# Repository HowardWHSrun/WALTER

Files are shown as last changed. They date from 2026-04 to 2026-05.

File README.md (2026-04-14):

# WALTER

**WALTER** = *Walking Alternating Tripod for Evolutionary Research* — a twelve-DOF hexapod (firmware, MuJoCo RL, CAD, and documentation).

**Authors (Engineering 90):** Howard Wang, Matthew Shiley  
**Advisor:** Allan Moser (Swarthmore College)

## Contents (repository map)

| Area | Path |
|---|---|
| Final report (PDF, LaTeX, figures) | [`final_report/`](final_report/) |
| Adaptive firmware and docs | [`adaptive_ondevice_hexapod/`](adaptive_ondevice_hexapod/) |
| MuJoCo PPO training code | [`hexapod_training_new/`](hexapod_training_new/) |
| Released checkpoints (zips) and eval helpers | [`e90_repo/`](e90_repo/) |
| Mid-semester presentation sources | [`Presentation/`](Presentation/) |

Training rollouts under `hexapod_training_new/runs/` are omitted from this repository to save space; regenerate with `train.py` and the configs in `hexapod_training_new/configs/`.

## Build the final report PDF

From `final_report/`:

```bash
pdflatex E90_Final_Report.tex
bibtex E90_Final_Report
pdflatex E90_Final_Report.tex
pdflatex E90_Final_Report.tex
```

A prebuilt `E90_Final_Report.pdf` is included. To regenerate the MuJoCo figure `mujoco_hexapod_sim.png`, install `mujoco` and `imageio`, `cd final_report`, and run `python3 render_mujoco_snapshot.py` (expects `../hexapod_training_new/assets/hexapod.xml` in this repository clone).

## License

Add a `LICENSE` file if you want explicit terms; otherwise default GitHub copyright applies.

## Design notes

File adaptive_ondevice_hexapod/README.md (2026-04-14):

# Adaptive on-device learning (hexapod)

**WALTER — canonical repository:** [https://github.com/HowardWHSrun/WALTER](https://github.com/HowardWHSrun/WALTER)  
*(Walking Alternating Tripod for Evolutionary Research. Consolidate firmware, docs, and CAD here for public release.)*

Bio-inspired hexapod that uses **IMU body-state feedback** to reflexively stabilize locomotion and **gradually adapt its gait** on-device, running entirely on a Teensy 4.1.

## Approach

Three layers, inspired by insect locomotion architecture:

1. **Innate rhythm** -- structured tripod gait (v2 lift/swing/plant keyframes).
2. **Sensory corrections** -- IMU-driven postural reflexes adjust leg targets in real time (roll/pitch stabilization, angular-velocity damping, cautious mode, push recovery).
3. **Online learning** -- slow adaptation of 5 reflex/gait parameters via SPSA or bandit search, minimizing a stability cost computed from IMU signals.

## Documentation

| Document | Contents |
|---|---|
| [docs/DESIGN.md](docs/DESIGN.md) | Biological motivation, what the IMU tells us, full behavior catalog (13 behaviors across 3 levels), limitations, references |
| [docs/ARCHITECTURE.md](docs/ARCHITECTURE.md) | Control loop diagram, IMU filter pseudocode, stability score, tuneable gait parameters, reflex rules, adaptation layer (SPSA), timing budget, safety limits |
| [docs/PHASES.md](docs/PHASES.md) | Four-phase implementation roadmap with concrete deliverables and exit criteria per phase |
| [docs/FIRMWARE.md](docs/FIRMWARE.md) | Hardware stack: Teensy 4.1, Pololu Maestro, 12 servos, channel map, Maestro protocol, joint-to-us mapping |

## Repo layout

| Path | Purpose |
|---|---|
| `docs/` | Design docs, architecture, roadmap, hardware reference |
| `firmware/hexapod_walking_v2/` | Baseline: hard-coded scripted tripod v2 gait (no adaptation) |
| `firmware/hexapod_imu_test/` | Phase 1: IMU filter + telemetry (created during implementation) |
| `firmware/hexapod_adaptive/` | Phases 2--4: reflexes, cautious mode, online learning (created during implementation) |
| `host/` | Optional PC tools (logging, analysis, flash scripts) |
| `sim/` | Optional MuJoCo / Python experiments |

## Hardware

- **MCU:** Teensy 4.1 (600 MHz Cortex-M7, hardware FPU)
- **Servo controller:** Pololu Maestro (UART, 9600 baud on `Serial1`)
- **Servos:** 12 (6 legs x 2 joints: abduction + flexion)
- **Sensor:** 6-axis IMU (I2C) -- BNO055, MPU-6050, or ICM-20948

## Implementation phases

1. **IMU filter + telemetry** -- wire IMU, complementary filter, print roll/pitch/rates. No gait changes.
2. **Postural reflexes** -- per-leg corrections from roll/pitch/rates. Hard-coded gains. Robot levels itself on slopes.
3. **Cautious mode + recovery** -- stability score triggers slower/shorter stride; push recovery reflex on angular velocity spikes.
4. **Online parameter learning** -- 5-scalar SPSA optimization of reflex gains and gait shape, EEPROM persistence.

See [docs/PHASES.md](docs/PHASES.md) for details, exit criteria, and the E90 story at each stage.

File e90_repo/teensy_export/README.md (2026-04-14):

# Teensy export prototype (ODE tripod)

## Tier A vs Tier B (what this folder supports)

| Tier | Deploy artifact | This repo |
|---|---|---|
| **A** | Open-loop or lightly scheduled gait using **constants** only (`ode_tripod_hyper.h`, `ode_tripod_nominal.h`) | Yes: hyperparameters and nominal mean action at `obs=0`, `t=0` as a **hint** for bring-up. Replace nominals with values you trust from sim or logging. |
| **B** | Tier A structure + **small actor MLP** on the Teensy (float32 or int8) | Yes: `ode_tripod_actor_weights.h` lists all Linear weights/biases and `log_std` (ignore `log_std` if you run deterministic mean-only). Implement ReLU + matmul in firmware to match PyTorch. |

**Tier B (quantized int8 / TFLite Micro)** is not auto-generated here: convert the same actor in PyTorch or ONNX with a separate quantization pipeline if flash/RAM requires it.

## Generate headers

From `e90_repo`:

```bash
python scripts/export_ode_tripod_teensy.py --checkpoint path/to/ppo_ode_tripod.zip --output-dir teensy_export
```

Optional: `--config configs/config_teensy_imu_compare.yaml` (reserved for future sanity checks; observation size is taken from the checkpoint).

Outputs:

- `ode_tripod_hyper.h` — frequency bounds, amplitude caps, signs, residual scale, observation dimensions.
- `ode_tripod_actor_weights.h` — `float` arrays for `_actor_core`, `_param_head`, `_residual_head`, `log_std`.
- `ode_tripod_nominal.h` — scalar hints and `ODE_TRIPOD_NOMINAL_ACTION_MEAN[12]` at zero observation.
- `export_meta.yaml` — small manifest.

## Firmware checklist

1. Match **control period** and observation layout to [docs/TEENSY_DEPLOY.md](../docs/TEENSY_DEPLOY.md).
2. Replicate `models/ode_gait/reference_from_phase.py` tripod indexing on the MCU (or call into shared C).
3. Forward pass order: `obs_core` → `_actor_core` (Linear+ReLU) → `_param_head` (4) and `_residual_head` (12); compute `theta = 2*pi*freq*t + phase_off`; `tripod_actions_from_phase` + `residual_scale * tanh(res)`; clip to [-1,1].
4. Keep **safety limits** outside the network path.

## Smoke test checkpoint

Untrained saves used for CI-style checks may be created with:

```bash
python -c "from pathlib import Path; import sys; sys.path.insert(0,'.'); \
from scripts.compare_tier_policies_imu import load_config, make_vec_env, fresh_ppo_ode; \
c=load_config('configs/config_teensy_imu_compare.yaml'); e=make_vec_env(c,0); m=fresh_ppo_ode(e,c,0); \
Path('teensy_export').mkdir(exist_ok=True); m.save('teensy_export/_smoke_ode_ppo.zip'); e.close()"
```

Then run `export_ode_tripod_teensy.py` on `_smoke_ode_ppo.zip`.

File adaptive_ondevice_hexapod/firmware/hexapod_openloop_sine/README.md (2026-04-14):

# Open-loop sinusoidal gait (no IMU)

**WALTER (project home):** [https://github.com/HowardWHSrun/WALTER](https://github.com/HowardWHSrun/WALTER)

Firmware implementation of `leg_commands()` from [`hexapod_no_imu_optimization.py`](../../hexapod_brain_roadmap%20copy/ode_optimization_no_imu/hexapod_no_imu_optimization.py): per-leg sinusoidal abduction and flexion with tripod anti-phase (FL/MR/RL vs FR/ML/RR).

## Files

- `hexapod_openloop_sine.ino` — Teensy sketch (Maestro on `Serial1`, same protocol as v2).
- `optimized_gait_params.h` — gait parameters (often generated, not hand-edited).
- `sync_gait_params_from_json.py` — regenerates `optimized_gait_params.h` from `hexapod_brain_roadmap copy/ode_optimization_no_imu/no_imu_optimization_summary.json` after you run `hexapod_no_imu_optimization.py`. Usage: `python3 sync_gait_params_from_json.py` from this folder (or pass path to a summary JSON).
- `OPENLOOP_OPTIMIZATION_REPORT.tex` / `OPENLOOP_OPTIMIZATION_REPORT.pdf` — LaTeX write-up of the no-IMU optimizer and firmware mapping; build with `pdflatex OPENLOOP_OPTIMIZATION_REPORT.tex`.

## Tuning

- **`OPT_LIFT_SWING_DEG_PEAK`** in `optimized_gait_params.h`: extra foot clearance during swing when `sin(abd_phase) > 0` (same as `LIFT_SWING_DEG_PEAK` in Python). Increase if feet drag; set to `0` to disable. If the robot shuffles backward, flip the lift test in the sketch (`sinAbd < 0` instead of `> 0`).
- **`ABD_CMD_PER_DEG` / `FLX_CMD_PER_DEG`** in the `.ino`: map optimizer degrees to abstract joint commands (same convention as [`hexapod_walking_v2`](../hexapod_walking_v2/hexapod_walking_v2.ino)). Adjust on the bench so motion stays within safe pulses and matches expected stride height.
- **`ABD_CMD_*` / `FLX_CMD_*` clamps**: hard limits before `jointToUs`.
- **`FREQ_RAMP_MS`**: linear ramp from 0 Hz to `OPT_FREQUENCY_HZ` after boot (default 3000 ms). Set to `0` to use full frequency from the first tick (`frequencyNow()`).

## Baseline

For discrete tripod keyframes, keep using [`firmware/hexapod_walking_v2`](../hexapod_walking_v2/).

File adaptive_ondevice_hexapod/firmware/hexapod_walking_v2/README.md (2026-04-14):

# Hexapod scripted tripod gait (v2)

**Hard-coded joint targets** (abstract command integers → `jointToUs` → Pololu Maestro), **lift → swing → plant** sub-phases per tripod group.

- **Board:** Teensy 4.1 (Arduino + Teensyduino).
- **Maestro:** `Serial1` @ 9600 baud — same protocol as [docs/FIRMWARE.md](../../docs/FIRMWARE.md).

This folder is the **baseline reference** for the adaptive on-device project: behavior here is fully scripted, not learned.

## Upload

Open `hexapod_walking_v2.ino` in Arduino IDE (or use `arduino-cli` with FQBN `teensy:avr:teensy41`). Keep **only this sketch** in the folder so the IDE does not merge other `.ino` files.

## Calibrate

Edit `servoCenter[]` and `servoDir[]` for your hardware. Tune `START_FLEX`, `LIFT_FLEX`, `PUSH_FLEX`, and swing/push abd offsets if the stride is too weak or feet drag.

## Note on comments

The file header still mentions early v2 `LIFT_FLEX = -300`; the **active constant** in this copy is `LIFT_FLEX = -120` per your pasted source.

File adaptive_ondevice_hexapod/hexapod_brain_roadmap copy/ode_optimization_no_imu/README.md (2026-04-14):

# No-IMU ODE Optimization

This folder contains a Python version of the "random initialization + ODE simulation + constrained optimization" workflow that you described from the MATLAB `ode45` and `fmincon` example, but adapted for the 12-servo tripod-coupled hexapod.

## What It Optimizes

**Primary objective:** maximize **mean forward velocity** (m/s) over the steady-state portion of the simulation (after an initial transient). Secondary terms penalize large roll/pitch, vertical oscillation, servo overload, and contact imbalance so solutions stay somewhat reasonable.

**Swing lift:** `leg_commands()` applies an extra flex reduction when `sin(abd_phase) > 0` (peak `LIFT_SWING_DEG_PEAK` degrees), analogous to the discrete lift phase in tripod v2 firmware, so simulated feet can clear the ground better than a bare sinusoid.

The optimizer treats the hexapod as a reduced no-IMU body model with:

- 6 abduction joints
- 6 flexion joints
- tripod A / tripod B phase coupling
- one global gait frequency

The decision vector is:

- 6 abduction rest angles
- 6 flexion rest angles
- 6 abduction phase shifts
- 6 flexion phase shifts
- 1 gait frequency

That is 25 optimization variables total.

## Physical Assumptions

The model assumes 12 SG90-like 9g servos and estimates total robot mass from:

- servo mass
- chassis mass
- battery and electronics mass

These values are easy to change in `hexapod_no_imu_optimization.py` if your robot mass is different.

## Run

```bash
python3 hexapod_no_imu_optimization.py
```

Multi-restart runs can be slow because each objective evaluation integrates the ODE. For a quicker exploration (coarser time grid), then deploy with `firmware/hexapod_openloop_sine/sync_gait_params_from_json.py`:

```bash
python3 hexapod_no_imu_optimization.py --restarts 4 --maxiter 80 --max-fun 350 --samples 400 --duration 5
```

Use full `--duration 8`, `--samples 800`, and higher `--max-fun` when you want a more accurate final pass (often with `--restarts 1` from the best seed found above).

Prioritize forward speed more strongly (default weight is 1000):

```bash
python3 hexapod_no_imu_optimization.py --forward-speed-weight 2000 --restarts 12
```

Optional soft floor on mean speed (penalizes solutions that stay below 0.10 m/s):

```bash
python3 hexapod_no_imu_optimization.py --target-speed 0.10 --target-speed-penalty-weight 400
```

## Outputs

Each run writes:

- `*_summary.json`
- `*_summary.md`
- `*_timeseries.csv`

## Notes

- This is a reduced ODE model for optimization and parameter search, not a full rigid-body simulator.
- The script keeps the tripod anti-phase structure from the roadmap and `hexapod_walking_v2_snapshot.ino`.
- The firmware values in the Arduino file look pulse-like rather than directly physical angles, so this Python model uses physically plausible degree-space variables for optimization.
# Hexapod ODE Optimization Without IMU

This folder contains a Python version of a `fmincon` + `ode45` style workflow for the 12-servo hexapod in `hexapod_walking_v2_snapshot.ino`.

## What it does

- models the 12 servos as coupled second-order ODEs
- uses the tripod grouping from the current walking code
- optimizes open-loop gait parameters without IMU feedback
- uses randomized initialization
- simulates with `scipy.integrate.solve_ivp` (Python analogue of `ode45`)
- optimizes with `scipy.optimize.minimize(method="SLSQP")` (Python analogue of `fmincon`)

## Optimized parameters

- front / middle / rear abduction rest angles
- front / middle / rear abduction angle shifts
- flexion rest angle
- flexion angle shift
- gait frequency
- tripod phase split for abduction
- tripod phase split for flexion
- flexion-abduction phase offset

## Modeling assumptions

- no IMU feedback, so this is an open-loop gait-parameter optimizer
- 12 servos total: 6 abduction + 6 flexion
- tripod groups match the existing code:
  - tripod A: `FL`, `MR`, `RL`
  - tripod B: `FR`, `ML`, `RR`
- servo model is a simplified second-order tracking model with damping, coupling, and gravity/load terms
- the robot mass and 9g-servo capability are included as coarse engineering assumptions, not measured hardware truths

## Default hardware assumptions in the script

- robot mass: `0.28 kg`
- 9g servo stall torque: `0.176 N*m`
- effective limb lever arm: `0.05 m`

These should be updated once you have measured values.

## Run

```bash
python3 optimize_hexapod_no_imu.py
```

## Python dependencies

- `numpy`
- `scipy`
- `matplotlib`

## Outputs

The script prints:

- best objective value
- identified dominant oscillation frequency
- optimized gait parameters

It also saves:

- `best_params_no_imu.json`
- `best_response_no_imu.png`

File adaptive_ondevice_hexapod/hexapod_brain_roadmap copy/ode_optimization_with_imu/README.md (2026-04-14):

# With-IMU Optimization

This folder is reserved for the next step of the hexapod model:

- add roll and pitch measurements from the IMU
- add reflex gains to the optimization variables
- compare no-IMU baseline versus IMU-stabilized gait tuning

For now, the implemented runnable optimizer is in `../ode_optimization_no_imu/`.
# Hexapod ODE Optimization With IMU

This folder is reserved for the next stage of the brain stack:

- closed-loop gait correction using IMU signals
- reward shaping from roll, pitch, and angular-rate penalties
- parameter adaptation on top of the open-loop no-IMU model

Suggested next files for this folder:

- `imu_signal_model.py`
- `closed_loop_hexapod_ode.py`
- `imu_reward_definition.md`
- `ppo_parameter_tuning_with_imu.py`

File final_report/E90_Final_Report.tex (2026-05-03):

% E90 Final Report — Howard Wang & Matthew Shiley; Advisor: Allan Moser
% Canonical project repository: https://github.com/HowardWHSrun/WALTER
% Build from this directory: pdflatex E90_Final_Report && bibtex E90_Final_Report && pdflatex E90_Final_Report && pdflatex E90_Final_Report

\documentclass[11pt]{article}
\usepackage[margin=1in]{geometry}
\usepackage[T1]{fontenc}
\usepackage[utf8]{inputenc}
\usepackage{lmodern}
\usepackage{setspace}
\usepackage{amsmath}
\usepackage{amssymb}
\usepackage{booktabs}
\usepackage{tabularx}
\usepackage{graphicx}
\usepackage{caption}
\usepackage{subcaption}
\usepackage{hyperref}
\usepackage[numbers,sort&compress]{natbib}

\hypersetup{colorlinks=true,linkcolor=blue,urlcolor=blue,citecolor=blue}
\setlength{\parskip}{0.5em}
\setlength{\parindent}{0pt}
\onehalfspacing
\emergencystretch=2em

\newcommand{\CourseName}{Engineering 90}
\newcommand{\StudentNames}{Howard Wang and Matthew Shiley}
\newcommand{\AdvisorNames}{Allan Moser, Francisco Valero-Cuevas, Will Johnson}
% Platform name: Walter (acronym W.A.L.T.E.R. = Walking Alternating Tripod for Evolutionary Research)
\newcommand{\ReportTitle}{Bio-Inspired Locomotion for \textit{Walter} (Walking Alternating Tripod for Evolutionary Research): CAD, Firmware, Optimization, MuJoCo Replay, and PPO}

\title{\ReportTitle}
\author{\StudentNames\\[0.5em]\CourseName\\Advisor(s): \AdvisorNames}
\date{\today}

\begin{document}
\maketitle

\begin{abstract}
\emph{Walter} (Walking Alternating Tripod for Evolutionary Research) is a twelve-degree-of-freedom hexapod built for this Engineering~90 capstone. The team fabricated a complete hardware platform: computer-aided-design models for the body, legs, and linkages; hobby servos; a Teensy~4.1 controller and Pololu eighteen-channel servo driver; SparkFun BMI270 inertial sensing; power regulation; and three iterations of custom \emph{Hexapod V2} printed circuit boards. On the control side, the project now includes two open-loop gait optimization methods, deterministic export of optimized gait parameters to firmware, deterministic replay of both optimized gaits in the MuJoCo physics simulator on flat, rough, and stepped terrain, and Proximal Policy Optimization policies trained in MuJoCo with inertial-observation configurations. The best bounded local-search open-loop replay moved an average of 1.78\,m forward across the three MuJoCo terrain tests, and the dual-annealing replay moved an average of 1.46\,m after applying a servo-realistic frequency cap. The strongest inertial-observation policy evaluation moved an average of 0.70\,m forward over three 1000-step MuJoCo episodes. The full layered adaptive firmware described in internal phase requirements, including inertial closed-loop reflexes and online adaptation on the microcontroller, was not completed on hardware; that stack remains future work. Overall, the capstone establishes a reproducible hexapod platform, two defensible optimized open-loop gait workflows, and simulation-based reinforcement-learning workflows with archived checkpoints and evaluation summaries. Materials are maintained at \url{https://github.com/HowardWHSrun/WALTER}. Purchased cost was US\$595.20 for electronics and US\$197.47 for printed-circuit-board orders, for a tracked total of US\$792.67; filament and fasteners are outside this sum.
\end{abstract}

\section{Introduction}

Reliable legged locomotion requires coordinating periodic limb motion with feedback under limited sensing and computation. Insects organize locomotor control in \emph{layers} that are standard in the literature: rhythmic coordination (often modeled as central-pattern-generator-like structure), fast sensory feedback, and slower parameter adjustment~\cite{aydin2023mechanosensory,chen2021adaptive}. This project uses that organization as bio-inspired control motivation, not as a claim that every layer is already running on hardware.

Framing of contributions. The strongest completed work is platform and methods: a reproducible hexapod with computer-aided design (CAD) documentation and custom printed circuit boards (PCBs); two open-loop gait optimization methods that export parameters to firmware; deterministic MuJoCo replay of those optimized gaits; and a Proximal Policy Optimization (PPO) training and evaluation workflow with inertial-observation runs, stored checkpoints, videos, and configs. A layered adaptive architecture using inertial measurement unit (IMU) fusion, reflexes, and slow adaptation is specified in design documents and informs observation choices in simulation, but it is not fully implemented on the physical hexapod. The report therefore emphasizes what was built and verified, and treats full adaptive locomotion on the robot as future engineering, not an accomplishment of this submission.

Bio-inspired elements (precise). The alternating tripod is a biologically motivated low-dimensional gait prior: two stance groups alternate before any learning is applied. IMU-based body-state cues (roll, pitch, rates) match how many legged systems use gravito-inertial information for posture~\cite{valenti2015quaternion,bai2019posture} and align the simulation observation stack with how \emph{Walter} is instrumented, which matters for eventual sim-to-real. Reinforcement learning in MuJoCo explores dynamics and reward shaping under that prior; it does not, by itself, close the hardware adaptive loop. Surrogate optimization of a compact sinusoidal law isolates an interpretable rhythm before sensor-heavy layers are added---consistent with separating pattern generation from feedback in many biological models~\cite{chen2021adaptive}, but realized here only through open-loop firmware.

Platform. The physical system is \emph{Walter}, a twelve-degree-of-freedom (DOF) hexapod with 3D-printed structure, servos, a Teensy microcontroller unit (MCU), Pololu servo driver, IMU, and \emph{Hexapod V2} PCBs (Sec.~\ref{sec:mech}--\ref{sec:elec}).

Code and report organization. Source code and this document are maintained at \url{https://github.com/HowardWHSrun/WALTER}. Sec.~\ref{sec:math-bg} states the optimization objective and the PPO machinery used in software. Sec.~\ref{sec:track1}--\ref{sec:track3} and Table~\ref{tab:tracks} summarize three tracks: (1)~open-loop optimization, firmware export, and MuJoCo replay using limited-memory Broyden--Fletcher--Goldfarb--Shanno with box constraints (L-BFGS-B) and dual annealing (completed); (2)~PPO locomotion in MuJoCo, including IMU-only and IMU-plus-phase observation modes (completed as a training/evaluation stack; limited hardware deployment); (3)~vision-augmented distance objectives (future work).

\section{Mathematical background: optimization and reinforcement learning}
\label{sec:math-bg}

Terminology. In this report, a \emph{surrogate} is a deliberately simplified model used for fast search. It is not the full robot and not the MuJoCo simulator: it is a reduced-order planar dynamics model that approximates body translation, body attitude, ground contact, and actuator-load proxies well enough to compare many candidate gait parameters quickly.

\subsection{Reduced-order gait optimization (Track~1)}
\label{sec:math-opt}

\subsubsection{Decision variables and bounds}
The optimization problem is to find a feasible gait parameter vector $\boldsymbol{\phi}$ that minimizes the scalar cost in Eq.~\eqref{eq:surrogate-cost}, subject to the box constraints listed below. The L-BFGS-B implementation acts on a vector $\boldsymbol{\phi}\in\mathbb{R}^{25}$ matching \texttt{hexapod\_no\_imu\_optimization.py}. Indices are concatenated as
\begin{equation}
  \boldsymbol{\phi} =
  \bigl(
  \boldsymbol{\theta}_{\mathrm{abd,rest}}^{\top},
  \boldsymbol{\theta}_{\mathrm{flx,rest}}^{\top},
  \boldsymbol{\delta}_{\mathrm{abd}}^{\top},
  \boldsymbol{\delta}_{\mathrm{flx}}^{\top},
  f
  \bigr)^{\top},
  \end{equation}
where each of $\boldsymbol{\theta}_{\mathrm{abd,rest}},\boldsymbol{\theta}_{\mathrm{flx,rest}},\boldsymbol{\delta}_{\mathrm{abd}},\boldsymbol{\delta}_{\mathrm{flx}}\in\mathbb{R}^{6}$ are in \emph{degrees} in the code (converted to radians internally), indexed by leg order front-left (FL), front-right (FR), middle-left (ML), middle-right (MR), rear-left (RL), rear-right (RR), and $f\in\mathbb{R}_{+}$ is the common gait frequency in hertz. Box constraints are implemented as \texttt{scipy.optimize.Bounds}: for example $f\in[0.4,\,4.0]$\,Hz; resting abduction per joint in $[-25^{\circ},25^{\circ}]$; resting flexion in $[10^{\circ},65^{\circ}]$; phase shifts in $[-120^{\circ},120^{\circ}]$. These define a feasible orthotope $\boldsymbol{\phi}_{\min}\le \boldsymbol{\phi}\le \boldsymbol{\phi}_{\max}$.

\subsubsection{Open-loop joint commands (sinusoidal law)}
Let $\omega=2\pi f$. For leg $\ell\in\{1,\ldots,6\}$ with fixed tripod offset $\psi_\ell\in\{0,\pi\}$ (alternating tripod), time $t\ge 0$, and fixed amplitude tables $\bar{a}_{\mathrm{abd},\ell}$, $\bar{a}_{\mathrm{flx},\ell}$ (defaults in code, not decision variables), the commanded abduction and flexion angles are
\begin{align}
  \phi_{\mathrm{abd},\ell}(t) &= \theta_{\mathrm{abd,rest},\ell}
    + \bar{a}_{\mathrm{abd},\ell}\,
      \sin\!\bigl(\omega t + \psi_\ell + \delta_{\mathrm{abd},\ell}\bigr), \\
  \phi_{\mathrm{flx},\ell}(t) &= \theta_{\mathrm{flx,rest},\ell}
    + \bar{a}_{\mathrm{flx},\ell}\,
      \sin\!\bigl(\omega t + \psi_\ell + \delta_{\mathrm{flx},\ell}\bigr)
    - \Delta_{\mathrm{lift},\ell}(t),
\end{align}
where $\Delta_{\mathrm{lift},\ell}$ implements swing-phase foot clearance (subtracting flexion when the abduction sine is positive), identical in structure to the firmware \texttt{LIFT\_SWING\_DEG\_PEAK} term. Velocities $\dot{\phi}_{\mathrm{abd},\ell}$, $\dot{\phi}_{\mathrm{flx},\ell}$ are obtained by differentiation and feed the planar surrogate dynamics.

\subsubsection{Surrogate planar dynamics and simulation}
The reduced model integrates an eight-dimensional state
\begin{equation}
  \mathbf{x}(t) =
  \bigl(x,\,\dot{x},\,z,\,\dot{z},\,\phi_{\mathrm{roll}},\,\dot{\phi}_{\mathrm{roll}},\,\phi_{\mathrm{pitch}},\,\dot{\phi}_{\mathrm{pitch}}\bigr)^{\top},
\end{equation}
with $\dot{\mathbf{x}}=\mathbf{f}(\mathbf{x},\boldsymbol{\phi})$ assembled from lumped masses, soft ground contact, leg thrust and support forces derived from $\phi_{\mathrm{abd},\ell}$, $\phi_{\mathrm{flx},\ell}$ and contact weights, and linear damping on body motion and attitude rates (\texttt{body\_ode} in the script). For fixed $\boldsymbol{\phi}$, the trajectory is obtained by \texttt{solve\_ivp} (Runge--Kutta) over $t\in[0,T]$ with $T$ the simulation horizon (\texttt{sim\_duration\_s}), sampled at $N$ time points (\texttt{sample\_count}).

\subsubsection{Scalar objective (explicit weighted sum)}
Let a subscript ``ss'' denote statistics evaluated on a \emph{steady-state} suffix of the horizon (the code uses the last 60\% of samples for oscillation metrics and mean speed). Write $\bar{v}_{x}$ for mean forward velocity $\mathbb{E}_{\mathrm{ss}}[\dot{x}]$, and root-mean-square (RMS) values $\mathrm{RMS}_{\mathrm{ss}}[\phi_{\mathrm{roll}}]$, $\mathrm{RMS}_{\mathrm{ss}}[\phi_{\mathrm{pitch}}]$, $\mathrm{RMS}_{\mathrm{ss}}[z]$. Let $q_{\mathrm{servo}}\ge 0$ be a slack on peak torque proxy exceeding a threshold (0.85 of stall in the implementation), and $\sigma_{\mathrm{contact}}$ the time mean of the per-timestep standard deviation of contact weights across legs. With nonnegative weights $w_{\cdot}$ matching \texttt{OptimizationConfig}, the implemented cost is
\begin{equation}
  \begin{aligned}
  \mathcal{J}(\boldsymbol{\phi}) &=
    -w_{\mathrm{fwd}}\,\bar{v}_{x}
    + w_{\mathrm{back}}\,\bigl[\max(0,-\bar{v}_{x})\bigr]^2 \\
  &\quad
    + w_{\mathrm{rp}}\Bigl(
        \mathrm{RMS}_{\mathrm{ss}}[\phi_{\mathrm{roll}}]^2
      + \mathrm{RMS}_{\mathrm{ss}}[\phi_{\mathrm{pitch}}]^2
      \Bigr)
    + w_{z}\,\mathrm{RMS}_{\mathrm{ss}}[z]^2 \\
  &\quad
    + w_{\mathrm{servo}}\,q_{\mathrm{servo}}^2
    + w_{\mathrm{contact}}\,\sigma_{\mathrm{contact}}^2
    + w_{\mathrm{reg}}\,\|\boldsymbol{\phi}-\boldsymbol{\phi}_{0}\|_{\mathrm{scaled}}^2 ,
  \end{aligned}
  \label{eq:surrogate-cost}
\end{equation}
where $\boldsymbol{\phi}_{0}$ is the default parameter vector and $\|\cdot\|_{\mathrm{scaled}}$ averages coordinatewise squared normalized deviation from the box midpoint (Tikhonov-style regularization keeping $\boldsymbol{\phi}$ in a ``reasonable'' neighborhood). Optional terms penalize shortfall below a target mean speed if \texttt{target\_forward\_speed\_mps}${}>0$. Infeasible simulations return a large penalty ($10^6$). Design intent: the weighted sum prioritizes forward progress while penalizing backward drift, attitude and vertical oscillation, actuator overload proxies, uneven leg loading, and deviation from nominal $\boldsymbol{\phi}_{0}$---a deliberate trade that can admit energetic gaits with visible body motion in the surrogate.

\subsubsection{Optimization algorithms and restarts}
The problem solved in software is
\begin{equation}
  \min_{\boldsymbol{\phi}}\ \mathcal{J}(\boldsymbol{\phi})
  \quad\text{subject to}\quad
  \boldsymbol{\phi}_{\min}\le \boldsymbol{\phi}\le \boldsymbol{\phi}_{\max}.
\end{equation}
L-BFGS-B (\texttt{scipy.optimize.minimize}, method \texttt{L-BFGS-B}) approximates curvature of $\mathcal{J}$ with a limited-memory inverse Hessian and projects each iterate onto the box. Each evaluation of $\mathcal{J}$ requires one numerical integration of the surrogate. The outer loop runs $R$ random restarts (\texttt{restarts}): one start at $\boldsymbol{\phi}_{0}$ and $R-1$ uniform samples in the box; the best $\boldsymbol{\phi}^\star$ by lowest $\mathcal{J}$ is retained. Limits \texttt{maxiter}, \texttt{maxfun}, and \texttt{ftol} cap work per restart.

Dual annealing was added as a second optimizer for the same open-loop gait family. It is a global stochastic method: early in the temperature schedule it can accept worse intermediate solutions, which helps it leave local minima, and then it refines promising regions. In this project dual annealing uses the same speed-versus-stability cost family but searches a slightly richer gait-shape parameterization, including amplitudes and lift magnitude. The resulting gait was more aggressive in the reduced model than the L-BFGS-B multistart result, so MuJoCo replay uses a servo-realistic frequency cap when evaluating it on terrain.

The code path from optimization to firmware is deterministic: $\boldsymbol{\phi}^\star$ is serialized to \path{no_imu_optimization_summary.json}; the sync script emits \path{optimized_gait_params.h}; and the open-loop sine sketch evaluates the same \texttt{leg\_commands()} map, applies bench degree-to-pulse gains and clamps, and streams servo targets. Thus optimization-to-code is \emph{algebraic parity}, not a learned policy. Both optimized open-loop controllers are also replayed directly in MuJoCo, which tests whether the optimized joint schedules remain upright and move forward in the higher-fidelity contact model before hardware trials.

\subsection{Policy optimization in MuJoCo (PPO with GAE)}
\label{sec:math-ppo}
Legged reinforcement learning is cast as a Markov decision process (MDP) with MuJoCo supplying transitions; we use actor--critic PPO as implemented in Stable-Baselines3~\cite{raffin2021stable}. The state can include proprioception, simulated base motion, or inertial channels depending on the configuration file. Generalized advantage estimation (GAE)~\cite{schulman2017proximal} builds advantages from temporal-difference (TD) residuals $\delta_t = r_t + \gamma V_\psi(s_{t+1}) - V_\psi(s_t)$:
\begin{equation}
  \hat{A}_t = \sum_{\ell=0}^{\infty}(\gamma\lambda)^\ell\,\delta_{t+\ell},
  \label{eq:gae}
\end{equation}
with $\lambda$ and discount $\gamma$ set in the configuration file. PPO~\cite{schulman2017proximal} stabilizes updates via a clipped ratio between the new and behavior policy. Define the probability ratio
\begin{equation}
  r_t(\theta)=\frac{\pi_\theta(a_t\mid s_t)}{\pi_{\theta_{\mathrm{old}}}(a_t\mid s_t)}.
\end{equation}
For continuous actions, $\pi_\theta$ is typically Gaussian; $r_t$ is the ratio of densities. The clipped surrogate objective for a batch of timesteps is
\begin{equation}
  \mathcal{L}^{\mathrm{CLIP}}(\theta)
  = \mathbb{E}_t\Bigl[
 \min\bigl(
      r_t(\theta)\,\hat{A}_t,\;
      \mathrm{clip}\bigl(r_t(\theta),1-\epsilon,1+\epsilon\bigr)\,\hat{A}_t
    \bigr)
  \Bigr],
  \label{eq:ppo-clip}
\end{equation}
with clip range $\epsilon\in(0,1)$ (often $0.2$). Large policy steps that inflate $r_t$ when $\hat{A}_t>0$ (or shrink $r_t$ when $\hat{A}_t<0$) are clipped so the effective objective stops increasing, reducing catastrophic updates common in vanilla policy gradients.

Let $\hat{R}_t$ denote a target return for the critic (e.g., $n$-step return or GAE-backed value target). With coefficients $c_v,c_e>0$, the composite loss maximized in practice is the negative of
\begin{equation}
  \mathcal{L}_{\mathrm{total}}(\theta,\psi)
  = -\mathcal{L}^{\mathrm{CLIP}}(\theta)
  + c_v\,\mathbb{E}_t\bigl[(V_\psi(s_t)-\hat{R}_t)^2\bigr]
  - c_e\,\mathbb{E}_t\bigl[H(\pi_\theta(\cdot\mid s_t))\bigr],
  \label{eq:ppo-total-loss}
\end{equation}
where $H$ is differential entropy for Gaussian policies. Minimizing $\mathcal{L}_{\mathrm{total}}$ corresponds to ascending $\mathcal{L}^{\mathrm{CLIP}}$ while fitting the critic and discouraging collapse of exploratory variance. Updates use minibatches over several epochs on each rollout buffer; hyperparameters (learning rate, rollout length \texttt{n\_steps}, batch size, $\gamma$, $\lambda$, $\epsilon$, $c_v$, $c_e$) are set in configuration files under \texttt{hexapod\_training\_new/configs/}.

\section{Track I: Open-loop optimization, MuJoCo replay, and firmware export}
\label{sec:track1}

This track implements Sec.~\ref{sec:math-opt}: the $\boldsymbol{\phi}$ parameterization, sinusoidal \texttt{leg\_commands()}, the eight-state surrogate, cost~\eqref{eq:surrogate-cost}, box-constrained L-BFGS-B with restarts, dual annealing as a second optimizer, and a deterministic path from optimized parameters to C headers and \texttt{hexapod\_openloop\_sine}. The workflow isolates a tunable open-loop rhythm before IMU-closed-loop layers are required.

What we shipped. Optimizer scripts, L-BFGS-B and dual-annealing JavaScript Object Notation (JSON) summary files, JSON-to-header sync, an open-loop Arduino sketch with exported gains, and deterministic MuJoCo terrain replays for both optimized gaits. Quantitative surrogate and replay outputs appear in Tables~\ref{tab:sim}--\ref{tab:mujoco-openloop}; the high-fidelity MuJoCo asset used for replay and learning appears in Fig.~\ref{fig:mujoco}.

\section{Track II: PPO locomotion with inertial observations in MuJoCo}
\label{sec:track2}

The policy $\pi_\theta(a|s)$ conditions on proprioception (joint positions and velocities), simulator base kinematics, and---in IMU-focused configuration files---accelerometer, gyroscope, and orientation-derived channels so roll, pitch, and body rates align with how \emph{Walter} is sensed on hardware. Tripod structure enters through phase features, structured policy heads, or reward shaping, depending on the experiment. Training uses Eqs.~\eqref{eq:gae}--\eqref{eq:ppo-clip} on MuJoCo rollouts.

Scope. The team built, trained, and evaluated policies in simulation, archived checkpoints, and wrote short evaluation summaries for representative runs (Table~\ref{tab:rl-eval}). Recent inertial-observation runs include \texttt{imu6\_001}, \texttt{imu\_bno10\_001}, and \texttt{imu\_bno10\_natural\_001}, each trained for about 303k MuJoCo timesteps. Deploying a trained policy as the primary closed-loop driver on the physical robot---with the same observation latency and actuation path as firmware---was out of scope for verification in this report.

\section{Track III: Vision-augmented distance objectives (future)}
\label{sec:track3}

Future work. Augment $s$ with visual odometry or pose from an overhead or onboard camera so rewards can emphasize distance traveled with less privileged state. Let $p_t\in\mathbb{R}^2$ be horizontal pose from visual integration or fiducials, and consider forward displacement $x_t-x_0$. A natural reward increment is
\begin{equation}
  r_t = \alpha\,(x_{t+1}-x_t) - \beta\,\|\omega_t\|^2 - \rho\,\mathrm{penalty}_{\mathrm{fall}} - \kappa\,\mathrm{TV}(a)_t,
\end{equation}
with IMU rates $\omega_t$ penalizing harsh attitude changes, optional terms for staying upright, and $\mathrm{TV}(a)_t$ denoting total variation in the action sequence. The observation becomes $s_t=[s_t^{\mathrm{IMU/proprio}},\, f_t]$ where $f_t$ is a vector of visual features or estimated pose; PPO then applies the same surrogate~\eqref{eq:ppo-clip} with expanded input dimension.

Open challenges include sim-to-real on vision, defining rewards from estimated versus ground-truth motion, and keeping a tripod prior while learning residuals.

\begin{table}[htbp]
  \centering
  \caption{Summary of the three development tracks for \emph{Walter}.}
  \label{tab:tracks}
  \begin{tabular}{@{}p{0.14\linewidth}p{0.46\linewidth}p{0.32\linewidth}@{}}
    \toprule
    Track & Technical core & Outcome in this capstone \\
    \midrule
    I & Surrogate $\mathcal{J}(\boldsymbol{\phi})$ \eqref{eq:surrogate-cost}; L-BFGS-B and dual annealing; MuJoCo open-loop terrain replay; JSON$\to$\texttt{.h}$\to$ firmware & Completed: two optimized gaits exported/evaluated; firmware path demonstrated \\
    II & PPO \eqref{eq:ppo-clip}; GAE \eqref{eq:gae}; MuJoCo env; IMU-only and IMU-plus-phase modes in config & Completed in simulation: training/eval pipeline, IMU-policy checkpoints, videos, and summaries; hardware policy deployment not fully exercised here \\
    III & Visual or pose features $f_t$; distance-centric rewards & Not started: specification and literature basis only \\
    \bottomrule
  \end{tabular}
\end{table}

\section{Technical Discussion}

\subsection{Biological and control context}
Decentralized feedback atop rhythmic coordination remains a standard idiom for insect locomotion~\cite{aydin2023mechanosensory,chen2021adaptive}. Attitude filters for accelerometer--gyro fusion~\cite{valenti2015quaternion,zhang2021attitude} and posture control on terrain~\cite{bai2019posture} inform the IMU observation choices in simulation. Disturbance-triggered transitions~\cite{johnson2010disturbance} motivate reflex layers in the design spec, not a completed hardware demo in this capstone.

\subsection{Planned adaptive layer (design specification)}
Internal architecture notes (\texttt{docs/ARCHITECTURE.md}) describe a future two-timescale stack: a fast tick ($\sim$10--20\,ms) for IMU read, attitude fusion, stability score $S$, reflex adjustments, gait interpolation, and servo commands; and a slow tick (per gait cycle) for windowed costs and optional parameter adaptation. That design informed IMU-inclusive observation modes in simulation, and PPO policies using those observation modes were trained in MuJoCo; the same closed-loop stack is not claimed as deployed firmware here. The complementary blend
\begin{equation}
\alpha \in (0,1),\quad
\theta_{\mathrm{roll}} \leftarrow \alpha(\theta_{\mathrm{roll}} + \omega_x \Delta t) + (1-\alpha)\,\theta_{\mathrm{roll,accel}},
\end{equation}
(and analogously for pitch) is the nominal attitude update.

\subsection{Open-loop sinusoidal gait (implemented)}
For the no-IMU milestone, each leg follows resting abduction and flexion angles plus sinusoidal variation at common frequency $f$, with tripod group~B offset by $\pi$ from group~A. This is the law optimized in Sec.~\ref{sec:math-opt} and delivered in Track~I (Sec.~\ref{sec:track1}). The L-BFGS-B workflow keeps the firmware-facing parameter vector compact, while the dual-annealing workflow searches a more aggressive gait shape and then constrains replay frequency when moved to MuJoCo.

\subsection{MuJoCo and reinforcement learning (simulation)}
High-fidelity testing uses Gymnasium + MuJoCo~\cite{todorov2012mujoco} in two ways: deterministic replay of optimized open-loop gaits, and PPO~\cite{schulman2017proximal} training as implemented in Stable-Baselines3~\cite{raffin2021stable}. For PPO, the mathematical objective is Eq.~\eqref{eq:ppo-clip} with advantages~\eqref{eq:gae}. Tracks~II--III (Sec.~\ref{sec:track2}--\ref{sec:track3}) specialize the observation and reward; configuration files set $\gamma$, $\lambda$, learning rate, network widths, proportional-derivative gains, and terrain. A representative static render of the simulation model appears in Fig.~\ref{fig:mujoco} (Sec.~\ref{sec:res-mujoco}).

\subsection{Mechanical design: CAD and 3D-printed parts}
\label{sec:mech}
Walter's chassis and legs are built from parts designed in CAD and produced by additive manufacturing (3D printing): a central body, six leg assemblies, and two-degree-of-freedom linkages per leg (abduction and flexion axes) that mate to the servo output splines. The design prioritizes a repeatable assembly for twelve actuated joints, clearance for wiring, and attachment of the electronics tray and battery. Figure~\ref{fig:walter} shows an overall render; Figure~\ref{fig:walter-parts} shows the body, leg, and linkage components used in the assembly. Fasteners and servo hardware complete the mechanical stack; material usage (filament mass) and printed-part cost are not included in the dollar totals in Tables~\ref{tab:cost}--\ref{tab:grand}.

\begin{figure}[htbp]
  \centering
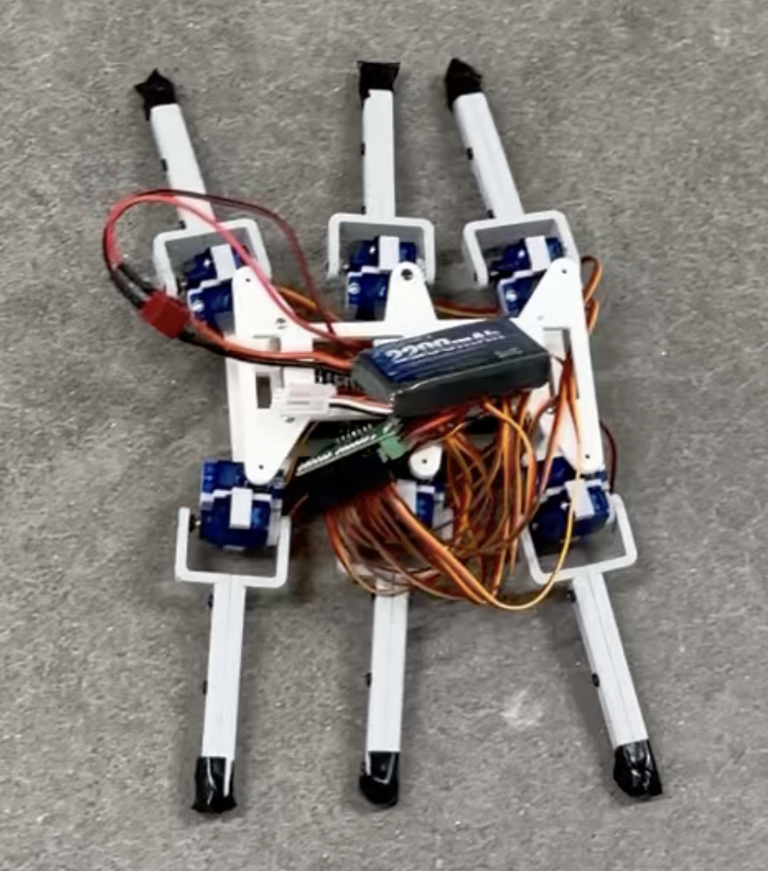
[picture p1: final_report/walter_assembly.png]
  
  \caption{Walter: full-assembly render of the twelve-DOF hexapod (CAD; Walking Alternating Tripod for Evolutionary Research).}
  \label{fig:walter}
\end{figure}

\begin{figure}[htbp]
  \centering
  \begin{subfigure}[b]{0.32\linewidth}
    \centering
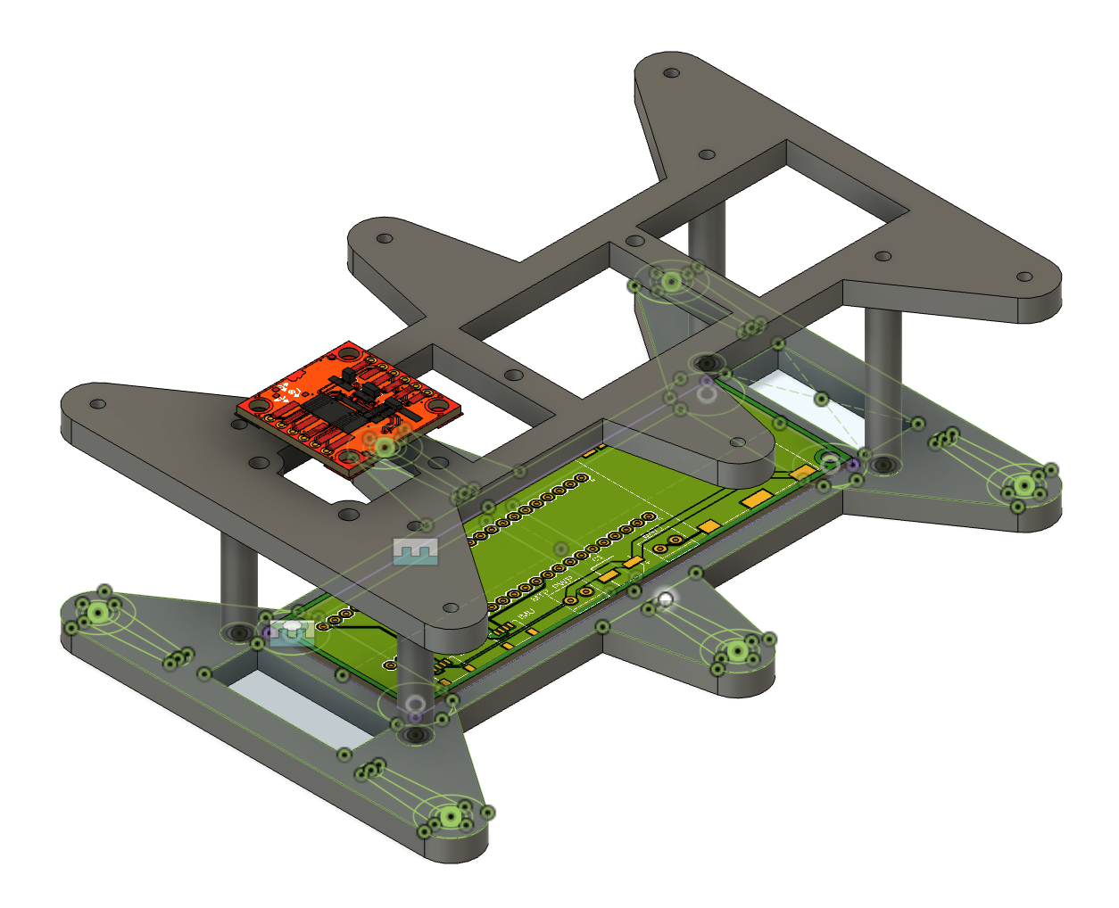
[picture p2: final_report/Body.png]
    
    \caption{Body}
  \end{subfigure}\hfill
  \begin{subfigure}[b]{0.32\linewidth}
    \centering
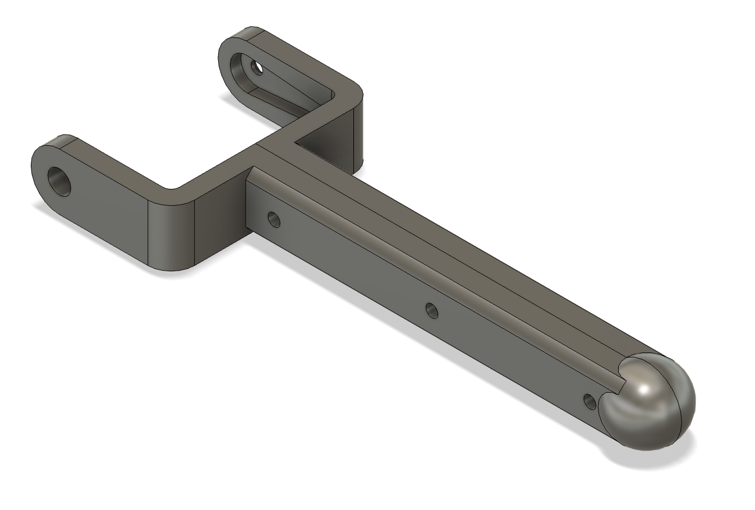
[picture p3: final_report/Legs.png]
    
    \caption{Leg assemblies}
  \end{subfigure}\hfill
  \begin{subfigure}[b]{0.32\linewidth}
    \centering
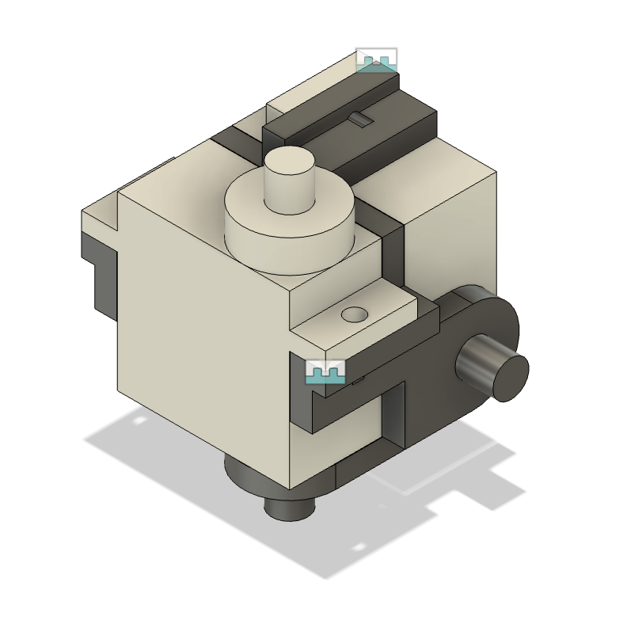
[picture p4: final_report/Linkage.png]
    
    \caption{Linkage}
  \end{subfigure}
  \caption{CAD-designed 3D-printed subassemblies for Walter: chassis, legs, and per-leg linkage.}
  \label{fig:walter-parts}
\end{figure}

\subsection{Electronics, Hexapod V2 PCB, and safety}
\label{sec:elec}
The bill of materials matches purchased components: Teensy-class MCU (SparkFun 16771), Pololu 1354 eighteen-channel driver, buck converter, BMI270 via Qwiic cabling, dual-cell lithium-polymer battery and charger, terminals, and servos. Custom \emph{Hexapod V2} PCBs (revision v5 dated 2026-04-03 on the latest order) integrate power and signal routing for Walter's stack; Figure~\ref{fig:pcb} shows a board photo and schematic excerpt. \texttt{docs/FIRMWARE.md} records universal asynchronous receiver/transmitter (UART) communication to the servo controller, channel ordering FL/FR/ML/MR/RL/RR with abduction then flexion per leg, and pulse mapping $u_k = \mathrm{clamp}(c_k + d_k q_k)$ (typical bounds 600--2400\,$\mu$s). Open-loop firmware applies degree-to-command gains and clamps before streaming compact-protocol targets; these bench gains are not outputs of the reduced-order optimizer.

\begin{figure}[htbp]
  \centering
  \begin{subfigure}[b]{0.48\linewidth}
    \centering
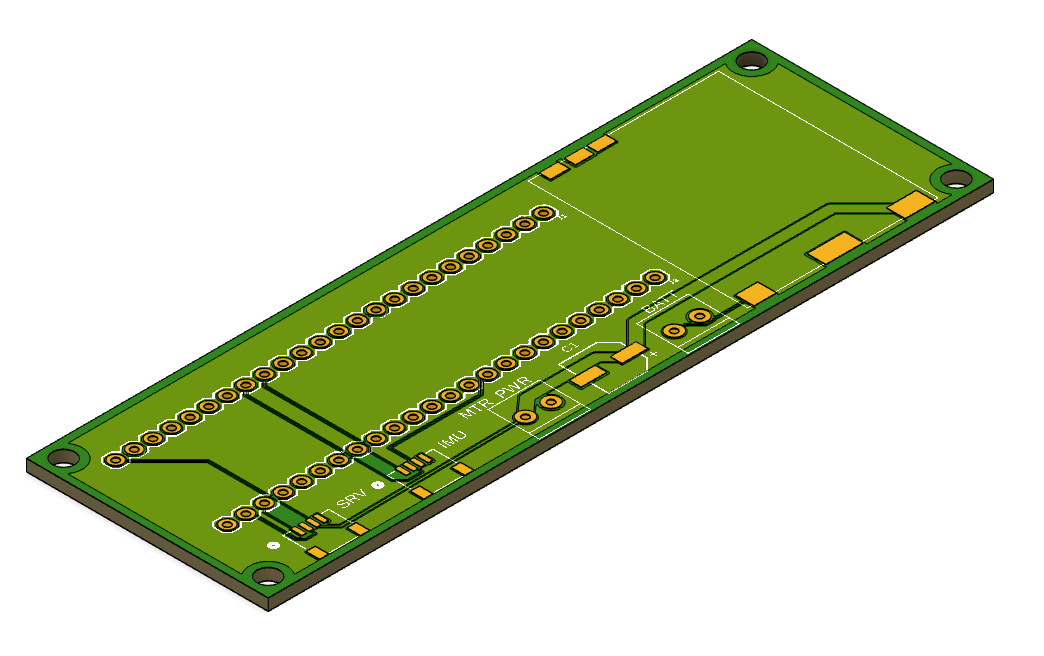
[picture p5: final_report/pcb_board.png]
    
    \caption{Assembled PCB (Hexapod V2)}
  \end{subfigure}\hfill
  \begin{subfigure}[b]{0.48\linewidth}
    \centering
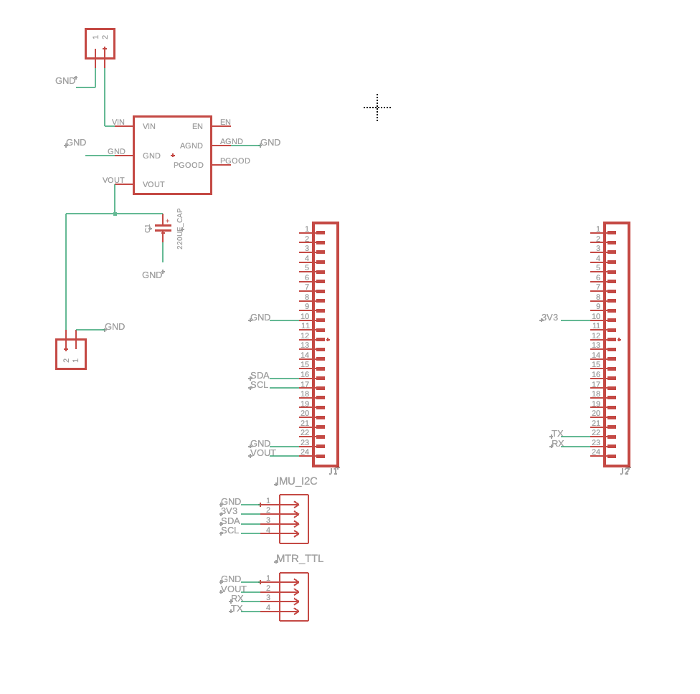
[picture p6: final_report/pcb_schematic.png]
    
    \caption{Schematic (excerpt)}
  \end{subfigure}
  \caption{Custom electronics for Walter: Hexapod V2 board and schematic.}
  \label{fig:pcb}
\end{figure}

\section{Requirements and Constraints}

\subsection{Source of requirements}
Engineering requirements are traced to phase exit criteria in \path{docs/PHASES.md} (Phases~1--4: IMU telemetry, reflexes, cautious mode and recovery, online adaptation), supplemented by safety and interface constraints in \path{docs/FIRMWARE.md} and the open-loop scope in \path{firmware/hexapod_openloop_sine/README.md}. \path{PHASES.md} serves as the team's consolidated requirements-and-constraints specification for firmware behavior.

\subsection{Summary: met vs.\ not met}
Satisfied in this project: discrete tripod baseline firmware; open-loop optimization with JSON export and header sync; MuJoCo replay of two optimized open-loop controllers; calibration sketches; CAD-documented mechanical design (Figs.~\ref{fig:walter}--\ref{fig:walter-parts}); a MuJoCo PPO workflow with configs, training scripts, checkpoints, videos, and evaluation writeups, including inertial-observation runs. Not satisfied against the internal phased firmware spec: Phases~1--4 adaptive behaviors (telemetry-only through online adaptation) are largely not implemented on the MCU in the snapshot summarized below.

For Table~\ref{tab:req}, Universal Serial Bus (USB) is the debugging and telemetry connection, electrically erasable programmable read-only memory (EEPROM) is the microcontroller nonvolatile parameter store, and simultaneous perturbation stochastic approximation (SPSA) is the planned lightweight adaptation optimizer.

\begin{table}[htbp]
  \centering
  \caption{Requirement traceability (internal \texttt{PHASES.md} vs.\ delivered work).}
  \label{tab:req}
  \begin{tabular}{@{}p{0.06\linewidth}p{0.36\linewidth}p{0.12\linewidth}p{0.38\linewidth}@{}}
    \toprule
    ID & Requirement & Status & Evidence / notes \\
    \midrule
    R1 & Phase~1: IMU read, complementary filter, USB telemetry $\sim$50\,Hz; gait unchanged & Not met (in repo) & \texttt{PHASES.md}; folder may be missing \\
    R2 & Phase~2: postural reflexes, clamps, serial tuning, EEPROM & Not met (in repo) & \texttt{ARCHITECTURE.md} pseudocode \\
    R3 & Phase~3: stability score, cautious mode, push recovery, fall freeze & Not met (in repo) & Documented only \\
    R4 & Phase~4: five-parameter adaptation, cost $J$, SPSA/bandit, EEPROM & Not met (in repo) & Documented only \\
    R5 & Hardware: MCU + eighteen-channel driver + servos + documented map + PCBs + Walter mechanical CAD/3D parts & Met & Bill of materials, Figs.~\ref{fig:walter}--\ref{fig:pcb}, \texttt{FIRMWARE.md} \\
    R6 & Safety: pulse clamps; parameter slew (adaptive layer) & Partial & Clamps in v2/openloop; slew in spec \\
    R7 & Open-loop: optimizer/firmware parity; JSON export; MuJoCo replay of optimized gait & Met & L-BFGS-B and dual-annealing summaries; \texttt{sync\_gait\_params\_from\_json.py}; open-loop MuJoCo eval folders \\
    R8 & Simulation: MuJoCo env, PPO training, IMU-observation runs, documented evals & Met & \texttt{hexapod\_training\_new/}, \texttt{runs/imu6\_001/}, \texttt{runs/imu\_bno10\_001/}, released checkpoints \\
    \bottomrule
  \end{tabular}
\end{table}

\subsection{Project cost}
Tables~\ref{tab:cost}--\ref{tab:pcb} summarize purchased electronics (three identical platforms) and fabrication costs for three PCB/stencil orders. Table~\ref{tab:grand} states the grand total for those categories only; filament, fasteners, and shop labor are outside the accounting. Servo counts in Table~\ref{tab:cost} are per platform (eight units listed per bill-of-materials line); completing twelve DOF per robot may require additional servos beyond those lines if not already stocked.

\begin{table}[htbp]
  \centering
  \caption{Electronics bill of materials, one platform (USD). The team purchased three identical sets.}
  \label{tab:cost}
  \footnotesize
  \setlength{\tabcolsep}{4pt}
  \begin{tabular}{@{}p{2.55cm}p{4.05cm}p{1.55cm}rrr@{}}
    \toprule
    Part & Description & Vendor & Qty & Unit & Line \\
    \midrule
    SparkFun 16771 & Microcontroller & DigiKey & 1 & 37.20 & 37.20 \\
    Pololu 1354 & 18-channel servo driver & DigiKey & 1 & 46.95 & 46.95 \\
    DFRobot DFR1202 & Step-down buck converter & DFRobot & 1 & 12.90 & 12.90 \\
    SparkFun BMI270 & 6-DoF IMU & DigiKey & 1 & 18.50 & 18.50 \\
    SparkFun 11855 & 2$\times$7.4\,V lithium-polymer battery + charger & Amazon & 1 & 27.99 & 27.99 \\
    SparkFun 14417 & Female Qwiic connector & DigiKey & 2 & 0.60 & 1.20 \\
    SparkFun 17259 & 100\,mm Qwiic cable & DigiKey & 1 & 1.95 & 1.95 \\
    SparkFun 17261 & Qwiic cable to female header & DigiKey & 1 & 1.95 & 1.95 \\
    Amphenol YO0201500000G & 1$\times$2 screw-down terminal & DigiKey & 2 & 1.28 & 2.56 \\
    DFRobot SER0039 & Servo motor & DigiKey & 8 & 5.90 & 47.20 \\
    \midrule
    Subtotal & one platform & & & & 198.40 \\
    Electronics total & three platforms ($\times$3) & & & & 595.20 \\
    \bottomrule
  \end{tabular}
\end{table}
\normalsize

\begin{table}[htbp]
  \centering
  \caption{PCB and stencil orders, \emph{Hexapod V2} (USD order totals including merchandise, shipping, duties/taxes, and sales tax where charged by the vendor).}
  \label{tab:pcb}
  \footnotesize
  \begin{tabular}{@{}p{3.1cm}p{4.6cm}p{2.0cm}r@{}}
    \toprule
    Order ID & Description / notes & Status & Total \\
    \midrule
    Y4-11911448A & PCB prototype (5\,pcs) + SMT stencil; v5\_2026-04-03 & Awaiting payment & 74.24 \\
    W2026030804205410 & PCB + stencil shipment & Shipped & 68.26 \\
    W2026021709554129 & PCB + stencil (earlier order) & Shipped & 54.97 \\
    \midrule
    PCB subtotal & & & 197.47 \\
    \bottomrule
  \end{tabular}
\end{table}
\normalsize

\begin{table}[htbp]
  \centering
  \caption{Grand total project cost (USD) for reported purchases and fabrication.}
  \label{tab:grand}
  \begin{tabular}{@{}lr@{}}
    \toprule
    Category & Amount \\
    \midrule
    Electronics (three platforms) & 595.20 \\
    PCB fabrication and stencils (three orders) & 197.47 \\
    \midrule
    Grand total & 792.67 \\
    \bottomrule
  \end{tabular}
\end{table}

\section{Methods}

\subsection{Mechanical assembly (\emph{Walter})}
Printed body and leg components are fastened per the CAD design; each leg receives two servos driving abduction and flexion through the linkage. The custom PCB mounts to the chassis and connects to the Pololu driver and Teensy; power and ground respect the buck converter and screw terminals from the bill of materials. Bench alignment uses \texttt{set\_zero} and side-only test sketches before closed-loop or open-loop gait tests.

\subsection{Baseline discrete gait}
\path{firmware/hexapod_walking_v2/hexapod_walking_v2.ino} implements a deterministic tripod state machine with smoothed keyframes (\texttt{moveSmoothTo}).

\subsection{Reduced-order simulation optimization}
\path{hexapod_brain_roadmap copy/ode_optimization_no_imu/hexapod_no_imu_optimization.py} integrates the surrogate model with \texttt{scipy.integrate.solve\_ivp}, evaluates the objective on a steady-state window, and calls \texttt{scipy.optimize.minimize} (L-BFGS-B). A second summary, \path{no_imu_optimization_da_summary.json}, records the dual-annealing result. Outputs include JSON summaries of optimized frequency, angles, phase shifts, lift, objective breakdowns, and optional comma-separated-value files and plots.

\subsection{Parameter sync and open-loop firmware}
From \path{firmware/hexapod_openloop_sine/}, run the sync script to regenerate \path{optimized_gait_params.h}. The sketch evaluates the sinusoidal law at \texttt{INTERP\_DELAY\_MS} (default 10\,ms), applies startup frequency ramping, maps degrees to integer commands, clamps, and sends Pololu compact-protocol targets on \texttt{Serial1}.

\subsection{MuJoCo replay of optimized open-loop gaits}
\texttt{hexapod\_training\_new} replays the optimized open-loop controllers in MuJoCo without training a policy. The replay maps firmware leg order front-left, front-right, middle-left, middle-right, rear-left, rear-right to the MuJoCo model order, applies the required abduction and flexion sign conventions, initializes the robot in the first gait pose, rate-limits target changes, and evaluates one 1000-step episode each on flat, rough, and stepped terrain. The L-BFGS-B gait is replayed at the firmware-capped 1.0\,Hz; the dual-annealing gait also uses a 1.0\,Hz cap because its raw 3.638\,Hz reduced-model optimum was too aggressive for terrain replay.

\subsection{Bench testing and calibration}
\texttt{firmware/set\_zero/} and side-only test sketches support calibration. The open-loop README documents sign and scale tuning when feet drag or the robot shuffles backward.

\subsection{MuJoCo PPO training and evaluation}
The project produced a reusable training workflow: \texttt{train.py} reads configuration files from \texttt{configs/}, writes summaries, checkpoints, and logs under \texttt{runs/<run\_name>/}, and pairs with \texttt{evaluate.py} using the same configuration. Inertial-observation runs use modes such as \texttt{imu6} and \texttt{imu\_bno10}, adding simulated accelerometer, gyroscope, and orientation-derived channels with configured noise. Released material includes zipped policies, per-run evaluation folders with summaries, plots, and videos, and metadata for reproducibility and reporting.

\section{Results}
\label{sec:results}

\subsection{Reduced-order optimization (surrogate model)}
Table~\ref{tab:sim} summarizes the two reduced-order optimizer outputs used later in MuJoCo replay. These numbers describe the \emph{planar surrogate} only; they are not a guarantee of on-robot speed or stability.

\begin{table}[htbp]
  \centering
  \caption{Optimizer-reported source metrics before MuJoCo replay.}
  \label{tab:sim}
  \footnotesize
  \setlength{\tabcolsep}{5pt}
  \begin{tabular}{@{}lrrrrrr@{}}
    \toprule
    Optimizer & $f$ (Hz) & Mean $v_x$ (m/s) & Travel (m) & Roll RMS (rad) & Lift (deg) & Cost \\
    \midrule
    L-BFGS-B multistart & 1.800 & 0.234 & 1.866 & 0.539 & 12.0 & $-226.24$ \\
    Dual annealing & 3.638 & 0.655 & 5.192 & 0.966 & 9.12 & $-630.90$ \\
    \bottomrule
  \end{tabular}
\end{table}
\normalsize

Reading Table~\ref{tab:sim}. Both optimizers found forward-moving source gaits in the reduced model. Dual annealing achieved a much higher surrogate speed and lower source cost, but it did so partly through high frequency and larger body motion. That is why MuJoCo replay, not the surrogate score alone, is used to judge whether the gait geometry transfers to a richer contact model. Pitch RMS remains near zero in both source files because the reduced planar model is symmetric; it should not be interpreted as a hardware pitch-stability claim.

Table~\ref{tab:opt-params} lists the L-BFGS-B $\boldsymbol{\phi}^\star$ exported to \texttt{optimized\_gait\_params.h}. Flexion phase shifts sit at the lower bound ($-90^\circ$): the optimizer traded stride phasing aggressively for the surrogate objective; bench tuning may move off that bound. Rest angles cluster in physically plausible ranges; frequency near $1.8$\,Hz matches a moderate stride rate for small hexapods in simulation-like settings. The dual-annealing gait is retained in its own JSON summary and replayed in MuJoCo, but the firmware header path currently uses the L-BFGS-B compact parameter set.

\begin{table}[htbp]
  \centering
  \caption{Optimized decision variables $\boldsymbol{\phi}^\star$ from L-BFGS-B (same JSON as Table~\ref{tab:sim}). Angles in degrees; leg order is front-left, front-right, middle-left, middle-right, rear-left, rear-right.}
  \label{tab:opt-params}
  \footnotesize
  \setlength{\tabcolsep}{6pt}
  \begin{tabular}{@{}p{3.5cm}p{9.2cm}@{}}
    \toprule
    Quantity & Value \\
    \midrule
    Gait frequency $f$ & 1.800\,Hz \\
    Abduction rest $\boldsymbol{\theta}_{\mathrm{abd,rest}}$ & $(10,\,10,\,0,\,0,\,-10,\,-10)$ \\
    Flexion rest $\boldsymbol{\theta}_{\mathrm{flx,rest}}$ & $(32.00,\,32.00,\,34.00,\,34.00,\,32.00,\,32.00)$ \\
    Abduction phase $\boldsymbol{\delta}_{\mathrm{abd}}$ & $\approx \mathbf{0}$ (magnitude $<10^{-6}$\,deg) \\
    Flexion phase $\boldsymbol{\delta}_{\mathrm{flx}}$ & $(-90,\,-90,\,-90,\,-90,\,-90,\,-90)$ \\
    Swing lift amplitude & 12.0\,deg (\texttt{lift\_swing\_deg\_peak}) \\
    \bottomrule
  \end{tabular}
\end{table}
\normalsize

\subsection{MuJoCo replay of optimized open-loop controllers}
Table~\ref{tab:mujoco-openloop} summarizes deterministic MuJoCo terrain tests for the two optimized open-loop controllers. Each row averages one 1000-step episode each on flat, rough, and stepped terrain. These are not learned policies; they are direct replays of optimized gait schedules after correcting leg-order and joint-sign conventions.

\begin{table}[htbp]
  \centering
  \caption{Optimized open-loop controllers replayed in MuJoCo terrain tests.}
  \label{tab:mujoco-openloop}
  \footnotesize
  \setlength{\tabcolsep}{4pt}
  \renewcommand{\arraystretch}{1.12}
  \begin{tabularx}{\linewidth}{@{}>{\raggedright\arraybackslash}p{2.7cm}rrrr>{\raggedright\arraybackslash}X@{}}
    \toprule
    Controller & Replay $f$ (Hz) & Mean $+x$ (m) & Mean $v_x$ (m/s) & Max tilt (deg) & Notes \\
    \midrule
    L-BFGS-B sine & 1.0 & 1.776 & 0.0844 & 5.68 & Stable across flat, rough, and stepped terrain; very small lateral drift and mean final yaw of 2.06$^\circ$. \\
    Dual annealing & 1.0 & 1.459 & 0.0705 & 6.20 & More aggressive source gait; frequency cap prevents the raw 3.638\,Hz optimum from becoming unrealistic in MuJoCo. \\
    \bottomrule
  \end{tabularx}
\end{table}
\normalsize

Reading Table~\ref{tab:mujoco-openloop}. The L-BFGS-B gait is less aggressive in the surrogate but transfers cleanly to MuJoCo terrain replay. The dual-annealing gait confirms that the second optimizer found usable gait geometry, but its source timing must be constrained for realistic replay. This is the clearest evidence that open-loop optimization is now running through the MuJoCo validation step rather than ending at a reduced-order score.

\subsection{MuJoCo simulation (high-fidelity model)}
\label{sec:res-mujoco}
Track~I--III testing uses Gymnasium with the MuJoCo asset \path{hexapod_training_new/assets/hexapod.xml}: checkerboard ground, twelve torque-controlled joints, and fourth-order Runge--Kutta (RK4) integration at 0.002\,s (see configs for frame skipping). Figure~\ref{fig:mujoco} is an offscreen MuJoCo render (software \texttt{Renderer}, no interactive viewer): the model was advanced under gravity with zero actuator commands until the body settled on the plane, then a fixed camera was used. The view documents the mesh, materials, and lighting used for open-loop replay and PPO rollouts; it is not a policy-controlled frame. Interactive inspection is available via \path{scripts/live_mujoco_viewer.py} with a trained checkpoint.

\begin{figure}[htbp]
  \centering
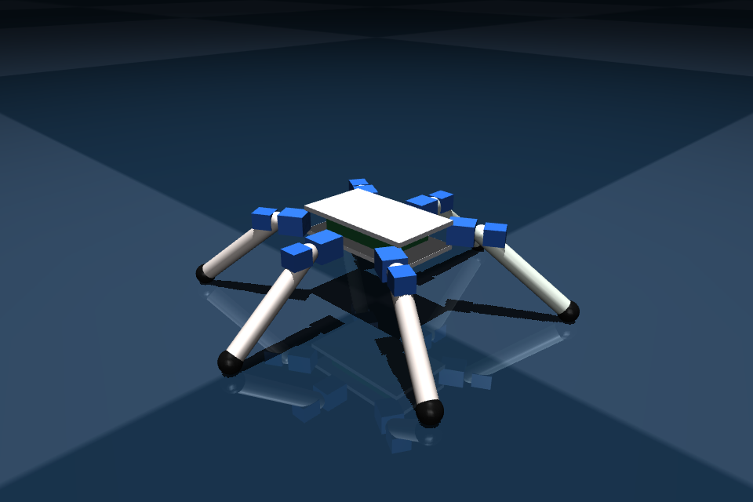
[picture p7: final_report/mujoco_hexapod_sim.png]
  
  \caption{MuJoCo screenshot of the Walter hexapod model used for open-loop replay, PPO training, and evaluation (post-settle, zero control; offscreen render).}
  \label{fig:mujoco}
\end{figure}

Figure~\ref{fig:mujoco} confirms the asset geometry and contact setup used for open-loop replay and learning; it is a passive settle, not evidence of policy quality. Training and evaluation videos for specific checkpoints provide the appropriate visual readout of learned behavior.

\subsection{MuJoCo PPO evaluations, including IMU policies}
Table~\ref{tab:rl-eval} quotes short evaluation protocols documented under \url{e90_repo/released_checkpoints/evaluations/} and \url{hexapod_training_new/runs/}. Rewards are not comparable across configs (different shaping and scaling); forward displacement and path length provide a common physical readout within each experiment family.

\begin{table}[htbp]
  \centering
  \caption{Representative PPO evaluation means. Episode length is 300 steps for the released checkpoint rows and 1000 steps for the IMU rows unless noted.}
  \label{tab:rl-eval}
  \footnotesize
  \setlength{\tabcolsep}{4pt}
  \renewcommand{\arraystretch}{1.15}
  \begin{tabularx}{\linewidth}{@{}>{\raggedright\arraybackslash}p{2.65cm} >{\raggedright\arraybackslash}X >{\raggedright\arraybackslash}p{1.25cm} >{\raggedright\arraybackslash}p{1.25cm} >{\raggedright\arraybackslash}X@{}}
    \toprule
    Checkpoint & Task / policy & Fwd.\,$+x$ & 2D path & Notes \\
    \midrule
    \url{mlp_clean_run005_best} & Circle path; multilayer perceptron (MLP) $256\!\times\!256$ PPO; training run \texttt{mlp\_run\_005} (301k steps). & 0.18\,m & 0.27\,m & Mean reward $\approx 6800$. \\
    \url{terrain_low_shake_run001_best} & Flat, rough, and step terrain; MLP PPO. & 0.33\,m (3 ep.\ mean) & --- & Flat/rough $\approx 0.47$\,m forward; steps harder. \\
    BNO10 IMU & MuJoCo PPO with ten-channel inertial observation mode; three video evaluation episodes. & 0.70\,m & 1.71\,m & Strongest IMU-policy row; mean reward $\approx 18{,}174$; run folder \path{imu_bno10_001}. \\
    BNO10 IMU + phase & Inertial observation plus phase feature; smoother/natural-action tuning. & 0.41\,m & 1.46\,m & Mean reward $\approx 14{,}448$; consistent forward progress across three episodes; run folder \path{imu_bno10_natural_001}. \\
    Six-channel IMU & Six-channel inertial observation; final-model MuJoCo video evaluation. & 0.089\,m & 0.186\,m & Demonstrates the PPO-IMU stack running in MuJoCo, but with modest forward progress; run folder \path{imu6_001}. \\
    \bottomrule
  \end{tabularx}
\end{table}
\normalsize

Reading Table~\ref{tab:rl-eval}. The rows are not comparable by raw reward (shaping and scaling differ). Forward displacement and path length are coarse physical readouts: the circle-path MLP run shows modest net forward motion and path length consistent with a curved task; the terrain run averages shorter forward progress when steps and roughness dominate; the inertial-observation rows show that PPO policies can be trained and evaluated in MuJoCo using simulated IMU-style inputs. The \texttt{imu\_bno10\_001} row is the strongest recent IMU result, while the \texttt{imu6\_001} row is best treated as a pipeline validation. Treat simulation displacements as indicative, not predictive of hardware distance without deployment tests.

The \texttt{pd\_velocity\_window\_run018\_best} checkpoint is a structured central-pattern-generator plus proportional-derivative velocity-window experiment with small net displacement in its released short evaluation---useful as an archival structured-policy datapoint, not a headline locomotion result (see that folder's \texttt{REPORT.md}).

\section{Discussion}

What this E90 demonstrates. The team built a named hexapod platform with documented mechanics, electronics, and cost; implemented an optimization-to-firmware path with two optimization methods; replayed the optimized open-loop controllers in MuJoCo; and ran a MuJoCo PPO training and evaluation workflow with archived checkpoints, videos, and IMU-observation configs. Together, that is a credible platform-and-methods outcome: reusable hardware, defensible open-loop pipelines, MuJoCo validation of optimized gait schedules, and simulation evidence for learned locomotion behaviors under stated rewards.

Why full adaptive locomotion is not claimed. Closing adaptive loops on hardware requires time for IMU bring-up, reflex tuning, safety testing, and power-aware deployment. The phased firmware requirements in \texttt{PHASES.md} were not met in the repository snapshot (Table~\ref{tab:req}); stating that once in requirements and here avoids repeating it in every technical subsection.

Technical bottlenecks. Surrogate versus MuJoCo versus hardware disagree on contact, friction, and servo dynamics; the dual-annealing source optimum illustrates this because its raw high frequency must be capped for MuJoCo terrain replay. Manual degree-to-pulse mapping separates optimized angles from reliable motion; open-loop gaits do not reject disturbances. Reinforcement-learning rewards are task-specific, so cross-comparing raw returns across configuration files is misleading---compare displacements and behaviors within a task family only, with humility about sim-to-real.

Sim claims. MuJoCo results show that optimized open-loop gait schedules and PPO policies \emph{can} run under the project's models and rewards. They are not automatic predictors of field performance without transfer experiments.

Credible next steps. Use the L-BFGS-B MuJoCo replay as the first hardware gait candidate; compare it against the dual-annealing geometry at conservative frequency; harden IMU read paths and logging on the Teensy; then pick one IMU-PPO checkpoint and measure a short hardware rollout with matched observation rate before adding vision or distance-only objectives.

Advice for future teams. Lock a baseline gait and logging format before layering sensors; budget bench time after every simulation milestone; track PCB revisions and BOM multiples from week one.

\section{Conclusion}

This capstone established \emph{Walter}: a twelve-DOF hexapod with CAD/3D-printed structure, custom PCBs, and purchased electronics totaling US\$792.67 in tracked spending. The team completed open-loop gait optimization with two methods, deterministic export to firmware, and MuJoCo replay of the optimized controllers. The team also completed a MuJoCo PPO training and evaluation toolchain with stored checkpoints, representative evaluations, and recent IMU-observation policy runs. A bio-inspired, layered adaptive control story informed design and simulation choices but was not fully realized on the MCU; that gap is documented in requirements traceability (Table~\ref{tab:req}) rather than hidden. The project provides a strong base for future adaptive and sim-to-real work; code and this report are maintained at \url{https://github.com/HowardWHSrun/WALTER}.

\section*{Acknowledgements}
We thank our advisor, Allan Moser, for guidance on the project. We thank Swarthmore Engineering and shop or lab staff who supported fabrication and testing. No funding sources beyond the Engineering department are declared for this accounting.

\bibliographystyle{ieeetr}
\bibliography{references}

\appendix
\section{Public repository}
\label{app:github}
The public project URL is \url{https://github.com/HowardWHSrun/WALTER}. Appendix paths below refer to the local Engineering~90 workspace layout at the time of writing; the GitHub repository is intended to subsume or mirror these components for reproducibility.

\section{Repository map (selected local paths)}
\begin{itemize}
  \item Adaptive firmware and docs: \path{adaptive_ondevice_hexapod/README.md}, \path{docs/DESIGN.md}, \path{docs/ARCHITECTURE.md}, \path{docs/PHASES.md}, \path{docs/FIRMWARE.md}
  \item Firmware sketches: \path{firmware/hexapod_walking_v2/}, \path{firmware/hexapod_openloop_sine/}, \path{firmware/set_zero/}, side-only tests
  \item Reduced-order optimization: \path{hexapod_brain_roadmap copy/ode_optimization_no_imu/}
  \item Open-loop sine replay: \path{runs/openloop_sine_mujoco_straight_firmware_terrain_001/}
  \item Dual-annealing replay: \path{runs/openloop_da_mujoco_straight_freqcap_terrain_001/}
  \item MuJoCo PPO training: \path{hexapod_training_new/} (\path{train.py}, \path{configs/}, \path{runs/})
  \item Recent IMU runs: \path{runs/imu6_001/}, \path{runs/imu_bno10_001/}, \path{runs/imu_bno10_natural_001/}
  \item Released checkpoints and evals: \path{e90_repo/released_checkpoints/}
  \item Presentation notes: \path{Presentation/E90_MidSemester_SpeakerScript.tex} and portable-document-format slides
  \item This folder (figures): \path{walter_assembly.png}, \path{Body.png}, \path{Legs.png}, \path{Linkage.png}, \path{pcb_board.png}, \path{pcb_schematic.png}, \path{mujoco_hexapod_sim.png}
\end{itemize}

\end{document}

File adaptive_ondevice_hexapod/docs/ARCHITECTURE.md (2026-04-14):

# Architecture: control loop on Teensy 4.1

This document shows how the IMU-based adaptive behaviors from [DESIGN.md](DESIGN.md) map to concrete code running on the Teensy alongside the v2 tripod gait.

## Loop structure

```mermaid
flowchart TD
    ReadIMU["Read IMU (I2C, ~500 Hz)"] --> Filter["Complementary / Mahony filter"]
    Filter --> Signals["roll, pitch, roll_rate, pitch_rate"]
    Signals --> StabilityScore["Compute stability score S"]
    StabilityScore --> Reflexes["Reflex layer: adjust gait params"]
    Reflexes --> GaitGen["Gait generator (v2 tripod keyframes)"]
    GaitGen --> SafetyClamp["Safety clamp (joint limits, slew)"]
    SafetyClamp --> Maestro["Write 12 channels to Maestro"]
    StabilityScore --> Adaptation["Adaptation layer (slow, every N cycles)"]
    Adaptation --> Reflexes
```

Two timescales run inside the same `loop()`:

| Timescale | Rate | What runs |
|---|---|---|
| **Fast tick** | Every `INTERP_DELAY` ms (~100 Hz) | IMU read, filter, reflex corrections, gait interpolation step, Maestro write |
| **Slow tick** | Every full gait cycle (~0.5--1 s) | Stability score windowed average, adaptation parameter update, optional EEPROM save |

## IMU filter

A complementary filter fuses accelerometer (noisy but drift-free) and gyroscope (clean but drifts) into roll and pitch estimates. On Teensy 4.1 (600 MHz Cortex-M7), this costs negligible cycles.

```
// Called every fast tick (dt ~ 10 ms or faster if IMU is polled at higher rate)
alpha = 0.98   // tuning knob: higher = trust gyro more, slower drift correction

accel_roll  = atan2(ay, az)
accel_pitch = atan2(-ax, sqrt(ay*ay + az*az))

roll  = alpha * (roll  + gx * dt) + (1 - alpha) * accel_roll
pitch = alpha * (pitch + gy * dt) + (1 - alpha) * accel_pitch

roll_rate  = gx   // or high-pass filtered gyro
pitch_rate = gy
```

Reference: complementary filter for embedded robots ([Zhang et al., 2021](https://www.mdpi.com/2072-666X/12/11/1373)).

For a Mahony filter (better under vibration), replace the linear blend with a proportional-integral correction on the cross product between measured and estimated gravity. Either works for this project; complementary is simpler to start.

## Stability score

A single scalar summarizing "how unstable is the robot right now":

```
S = w1 * |roll| + w2 * |pitch| + w3 * |roll_rate| + w4 * |pitch_rate|
```

Default weights (tune empirically):

| Weight | Default | Rationale |
|---|---|---|
| w1 | 1.0 | Roll angle (rad) |
| w2 | 1.0 | Pitch angle (rad) |
| w3 | 0.3 | Roll rate (rad/s); scale so units are comparable to angle |
| w4 | 0.3 | Pitch rate (rad/s) |

For the adaptation layer, also compute **windowed RMS** over the last `M` gait cycles:

```
S_rms = sqrt( (1/N) * sum(S_i^2) )   // N = samples in window
```

## Tuneable gait parameters

These v2 constants (currently `const int` in [hexapod_walking_v2.ino](../firmware/hexapod_walking_v2/hexapod_walking_v2.ino)) become **runtime variables** that the reflex and adaptation layers can adjust:

| Parameter | v2 default | What it controls | Adaptation knob |
|---|---|---|---|
| `LIFT_FLEX` | -120 | Step height (how far the foot lifts in swing) | Increase magnitude on rough terrain |
| `FRONT_SWING_ABD` | 110 | Front stride length | Scale down when unstable |
| `MID_SWING_ABD` | 85 | Mid stride length | Scale down when unstable |
| `REAR_SWING_ABD` | 110 | Rear stride length | Scale down when unstable |
| `INTERP_DELAY` | 10 | Speed of each interpolation step (ms) | Increase to slow gait |
| `LIFT_STEPS` | 10 | Lift sub-phase duration | Increase for more cautious lift |
| `SWING_STEPS` | 16 | Swing sub-phase duration | Increase to slow swing |
| `START_FLEX` | 1400 | Neutral body height | Per-leg bias for leveling |
| `PUSH_FLEX` | 1650 | Stance push depth | Reduce if legs bottom out on slopes |
| Gait mode | tripod | Pattern selection | Switch to slower pattern when S high |

In firmware these become fields in a `GaitState` struct:

```cpp
struct GaitState {
    int lift_flex;
    int push_flex;
    int start_flex;
    float stride_scale;      // 0.0 .. 1.0, multiplies SWING_ABD / PUSH_ABD
    float step_height_scale; // 0.5 .. 2.0, multiplies lift_flex magnitude
    int interp_delay;
    int lift_steps;
    int swing_steps;
    int plant_steps;
    int push_steps;
};
```

## Reflex rules (Level 1 behaviors)

### Roll/pitch stabilization (Behavior 1)

Distribute a per-leg flex bias so the body levels:

```
// Left legs: FL (ch 1), ML (ch 5), RL (ch 9)
// Right legs: FR (ch 3), MR (ch 7), RR (ch 11)

roll_correction = K_roll * roll    // positive roll = leaning right

left_flex_bias  = +roll_correction   // left legs push harder (more flex = more down)
right_flex_bias = -roll_correction   // right legs push less

// Front legs: FL (ch 1), FR (ch 3)
// Rear legs:  RL (ch 9), RR (ch 11)

pitch_correction = K_pitch * pitch   // positive pitch = nose down

front_flex_bias = -pitch_correction  // front legs push less
rear_flex_bias  = +pitch_correction  // rear legs push harder
```

Each leg's flex target becomes `base_flex + left_or_right_bias + front_or_rear_bias`. Clamp the result to safe range.

### Angular-velocity damping (Behavior 2)

Add a derivative term alongside the proportional roll/pitch correction:

```
roll_correction  = K_roll * roll  + K_droll * roll_rate
pitch_correction = K_pitch * pitch + K_dpitch * pitch_rate
```

This makes the reflex anticipatory: it reacts to the *rate* of tipping before the angle grows large.

### Cautious mode trigger (Behavior 3)

```
if (S_rms > S_CAUTIOUS_THRESH for N_CAUTIOUS_CYCLES consecutive cycles):
    stride_scale    *= 0.7      // shorten stride
    interp_delay    += 3        // slow down
    step_height_scale *= 1.2    // lift higher for safety
    // optionally switch to ripple or wave gait

if (S_rms < S_NORMAL_THRESH for N_NORMAL_CYCLES):
    gradually restore defaults
```

Hysteresis between thresholds prevents rapid switching.

### Terrain leveling (Behavior 4)

Same math as Behavior 1 but applied to `START_FLEX` rather than transient bias:

```
front_start_flex = START_FLEX - K_level * pitch
rear_start_flex  = START_FLEX + K_level * pitch
left_start_flex  = START_FLEX + K_level * roll
right_start_flex = START_FLEX - K_level * roll
```

This shifts the **neutral standing height** per leg pair so the chassis stays level on a slope.

### Push recovery (Behavior 9)

```
if (|roll_rate| > PUSH_THRESH or |pitch_rate| > PUSH_THRESH):
    enter RECOVERY mode for 2 gait cycles:
        stride_scale     = 0.5
        interp_delay     += 5
        step_height_scale = 1.5
        start_flex       += 100    // lower body
    then ramp back to normal over 2 more cycles
```

## Adaptation layer (Level 3 online learning)

### Parameter vector

Five scalars the robot learns online:

```
theta = { K_roll, K_pitch, stride_scale_base, step_height_scale_base, freq_scale }
```

These set the **baseline** for reflex gains and gait shape; the reflex layer still applies instantaneous corrections on top.

### Cost function

Evaluated once per gait cycle (or per `M`-cycle window):

```
J = a * RMS(roll)
  + b * RMS(pitch)
  + c * mean(|roll_rate| + |pitch_rate|)
  + d * gait_cycle_count_penalty       // penalize if fewer cycles completed (fell)
  // - e * forward_progress             // if available from secondary sensor or stride count
```

Without a forward-progress sensor, omit the last term and accept that the robot optimizes for stability only. Forward progress can be approximated coarsely from stride count times stride_scale.

### Update rule

**SPSA (Simultaneous Perturbation Stochastic Approximation):** perturb all 5 parameters with random +/- delta, run one window, measure J; perturb the other way, measure J; estimate gradient; step.

```
delta = random_signs(5) * perturbation_size

theta_plus  = theta + delta
theta_minus = theta - delta

// Run M gait cycles with theta_plus, measure J_plus
// Run M gait cycles with theta_minus, measure J_minus

gradient_estimate = (J_plus - J_minus) / (2 * delta)   // element-wise
theta = theta - learning_rate * gradient_estimate

// Clamp theta to safe bounds
```

Each "trial" is `M` gait cycles (~5--10 seconds). The robot tries two parameter sets, keeps the better direction, and slowly converges.

**Alternative: epsilon-greedy bandit** over a discretized grid of parameter combos (simpler, no gradient, works well for 5 dimensions if the grid is coarse).

### EEPROM persistence

```
if (J_current < J_best):
    J_best = J_current
    theta_best = theta
    save theta_best to EEPROM (same pattern as existing hexapod_walking_rl EEPROM code)
```

On boot, load `theta_best` from EEPROM as starting point.

## Timing budget

All times estimated for Teensy 4.1 (600 MHz Cortex-M7, hardware FPU):

| Task | Time per call | Frequency |
|---|---|---|
| IMU read (I2C @ 400 kHz) | ~0.5 ms | Every fast tick |
| Complementary filter | ~0.01 ms | Every fast tick |
| Stability score + reflex math | ~0.05 ms | Every fast tick |
| Gait interpolation + buildPose | ~0.05 ms | Every fast tick |
| Maestro write (12 channels) | ~1.5 ms | Every fast tick |
| **Total per fast tick** | **~2.1 ms** | |
| Available budget per tick | 10 ms (`INTERP_DELAY`) | |
| **Headroom** | **~7.9 ms** | |

The adaptation layer runs once per gait cycle (every ~500--1000 ms) and adds negligible cost (a few multiplies and one EEPROM write occasionally).

## Safety

All adaptive adjustments are bounded:

| Parameter | Hard min | Hard max | Max change per cycle |
|---|---|---|---|
| `lift_flex` | -400 | 0 | 50 per cycle |
| `push_flex` | 1200 | 1800 | 50 per cycle |
| `start_flex` | 1000 | 1600 | 30 per cycle |
| `stride_scale` | 0.3 | 1.0 | 0.1 per cycle |
| `step_height_scale` | 0.5 | 2.0 | 0.2 per cycle |
| `interp_delay` | 5 | 25 | 2 per cycle |
| `K_roll`, `K_pitch` | 0.0 | 500.0 | 50 per cycle |

**Fall detection:** if `|roll| > 45 deg` or `|pitch| > 45 deg`, freeze all servos at current position and enter safe mode (stop gait, print diagnostic over Serial). Require manual restart or Serial command to resume.

**Slew rate:** no parameter jumps from one gait cycle to the next beyond the max-change column. Ramp toward target values.

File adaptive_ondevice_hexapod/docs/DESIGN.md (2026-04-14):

# Design: IMU-based adaptive locomotion

## Biological motivation

Insect locomotion is modeled as **decentralized, feedback-driven, and layered**: a basic locomotion pattern produces rhythmic output, sensory corrections modulate that pattern in real time, and slower adaptation tunes the corrections over experience. This project follows the same layering on a 12-DOF hexapod with a single IMU as the primary exteroceptive sensor. The approach is grounded in mechanosensory control of locomotion in animals and robots ([Aydin et al., 2023](https://pmc.ncbi.nlm.nih.gov/articles/PMC10445419/)) and bio-inspired adaptive hexapod locomotion ([Chen et al., 2021](https://www.frontiersin.org/journals/neurorobotics/articles/10.3389/fnbot.2021.627157/full)).

The most bio-inspired use of the IMU is **not** inverted-pendulum balance. It is: **use body-state feedback to modulate an existing gait** -- the same principle insects use when mechanoreceptors adjust leg timing and force in response to body perturbation.

## What the IMU tells us

From a 6-axis IMU (accelerometer + gyroscope), filtered with a complementary or Mahony attitude estimator, we can reliably obtain:

| Signal | Source | Notes |
|---|---|---|
| Roll angle | Accel + gyro fusion | Trustworthy; no magnetometer needed |
| Pitch angle | Accel + gyro fusion | Trustworthy |
| Roll rate | Gyro (high-pass or direct) | Fast, good for reflexes |
| Pitch rate | Gyro (high-pass or direct) | Fast, good for reflexes |
| Vertical oscillation magnitude | Accel z-axis envelope | Proxy for gait smoothness |
| Sudden disturbance / impact | Accel norm spike or gyro spike | Trigger for recovery reflex |
| Trend: is stability degrading? | Windowed RMS of above signals | Drives adaptation layer |

Roll and pitch are far more reliable and useful than yaw for locomotion when no clean magnetometer is available, since magnetic disturbance and drift primarily corrupt heading estimation ([Valenti et al., 2015](https://www.mdpi.com/1424-8220/15/8/19302)). Hexapod posture-control work specifically uses body orientation and angular velocity as key stability variables on irregular terrain ([Bai et al., 2019](https://www.cambridge.org/core/journals/robotica/article/development-and-implementation-of-a-new-approach-for-posture-control-of-a-hexapod-robot-to-walk-in-irregular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)).

## Behavior catalog

### Level 1 -- Must-have (easy, high impact)

| # | Behavior | IMU signals used | Description |
|---|---|---|---|
| 1 | **Roll/pitch stabilization** | roll, pitch | If the body leans, adjust per-leg flex targets to bring it back. Increase stance on the falling side, reduce on the rising side. Clearest postural reflex. |
| 2 | **Angular-velocity damping** | roll rate, pitch rate | React to *how fast* the robot is tipping, not only final angle. Intervene before the angle becomes large. More reflex-like: responds to ongoing destabilization. |
| 3 | **Cautious mode trigger** | stability score (composite) | If the body oscillates too much, switch to a slower or more stable gait: reduce frequency, shorten stride, or switch pattern (tripod to ripple). Sensory state changes the locomotor pattern. |
| 4 | **Terrain compensation / body leveling** | roll, pitch | On a slope or uneven surface, change per-leg extension to keep the body level rather than rigidly following a flat-ground gait. |

### Level 2 -- Good project features (realistic, makes the robot feel intelligent)

| # | Behavior | IMU signals used | Description |
|---|---|---|---|
| 5 | **Step-height adaptation** | pitch spikes, accel impacts | If body shocks or pitch spikes increase during swing/landing, raise step height for the next few steps. Interpretation: "I am hitting stuff." |
| 6 | **Stride-length adaptation** | stability score trend | If roll/pitch instability grows, reduce stride length. Interpretation: "smaller steps are safer." |
| 7 | **Duty-factor adaptation** | stability score | Spend a larger fraction of each cycle in stance when unstable. Keep more legs on the ground longer. |
| 8 | **Frequency adaptation** | stability score, oscillation magnitude | If the body resonates or bounces, reduce gait frequency. Treats locomotion as a dynamic body-controller interaction. |
| 9 | **Push recovery reflex** | angular velocity spike | On sudden angular velocity spike, enter temporary recovery: slower motion, wider support, lower center of mass, longer stance. 1--2 gait cycles. |
| 10 | **Phase reset / timing correction** | body state mid-cycle | If body state becomes bad during a gait cycle, delay or advance the next swing phase instead of blindly following the metronome. |

### Level 3 -- Ambitious (strongest "bio-inspired learning" angle)

| # | Behavior | IMU signals used | Description |
|---|---|---|---|
| 11 | **Learn reflex gains online** | all of the above | Instead of hard-coding correction strength, let the robot learn: how strongly to react to roll, pitch rate, how much to shorten stride, raise step height. Low-dimensional and interpretable. |
| 12 | **Learn gait selection by context** | windowed IMU statistics | Store different "best parameter sets" for flat floor, incline, soft surface, disturbed condition. Select among them from recent IMU statistics. |
| 13 | **Learn stability cost minimization** | composite cost J | Define J = a * RMS(roll) + b * RMS(pitch) + c * angular_velocity - d * forward_progress. Tune gait parameters to reduce J. Clear engineering objective and clean experimental section. |

## What to avoid

- **Do not rely heavily on yaw** unless you have a well-calibrated magnetometer free from motor and wiring interference. Low-cost IMUs need sensor fusion, and magnetic disturbance mainly contaminates heading ([Zhang et al., 2021](https://www.mdpi.com/2072-666X/12/11/1373)).
- **Do not assume the IMU can directly sense foot contact.** It can hint at impacts and instability, but it is not a direct foot sensor.
- **Do not try to learn raw servo commands from scratch.** On this platform, that is harder to stabilize, harder to explain, and less biologically grounded than learning a few meaningful gait parameters ([Chen et al., 2021](https://www.frontiersin.org/journals/neurorobotics/articles/10.3389/fnbot.2021.627157/full)).

## Bio-inspired framing (for the report)

The strongest themes for E90:

- **Postural reflexes** -- the body senses tipping and changes limb output.
- **State-dependent gait modulation** -- the robot changes locomotion based on body state.
- **Layered control** -- innate rhythm first, sensory corrections second, learning third.
- **Embodied adaptation** -- the robot responds to body dynamics as they happen, not purely in software.

These align better with biology than "we used reinforcement learning to control 12 servos directly."

## References

1. Zhang, R. et al. (2021). Attitude Estimation Algorithm of Portable Mobile Robot Based on Complementary Filter. *Micromachines*, 12(11), 1373. [Link](https://www.mdpi.com/2072-666X/12/11/1373)
2. Aydin, Y. et al. (2023). Mechanosensory Control of Locomotion in Animals and Robots: Moving Forward. *PMC*. [Link](https://pmc.ncbi.nlm.nih.gov/articles/PMC10445419/)
3. Bai, L. et al. (2019). Development and implementation of a new approach for posture control of a hexapod robot to walk in irregular terrains. *Robotica*. [Link](https://www.cambridge.org/core/journals/robotica/article/development-and-implementation-of-a-new-approach-for-posture-control-of-a-hexapod-robot-to-walk-in-irregular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)
4. Chen, G. et al. (2021). Adaptive Locomotion Control of a Hexapod Robot via Bio-Inspired Learning. *Frontiers in Neurorobotics*. [Link](https://www.frontiersin.org/journals/neurorobotics/articles/10.3389/fnbot.2021.627157/full)
5. Johnson, A. et al. (2010). Disturbance Detection, Identification, and Recovery by Gait Transition in Legged Robots. *IROS 2010*. [Link](https://kodlab.seas.upenn.edu/uploads/Aaron/JohnsonAaronDisturbanceIROS2010.pdf)
6. Valenti, R.G. et al. (2015). Keeping a Good Attitude: A Quaternion-Based Orientation Filter for IMUs and MARGs. *Sensors*, 15(8), 19302. [Link](https://www.mdpi.com/1424-8220/15/8/19302)

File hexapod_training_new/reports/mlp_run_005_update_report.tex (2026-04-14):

\documentclass[10pt]{article}
\usepackage[margin=0.9in]{geometry}
\usepackage{booktabs}
\usepackage{hyperref}
\usepackage[T1]{fontenc}
\usepackage{lmodern}

\title{Concise Update: Baseline MLP \texorpdfstring{$\rightarrow$}{->} MLP Run 005}
\author{Hexapod RL Project}
\date{\today}

\begin{document}
\maketitle
\small

\section*{Goal}
Improve realism of servo-driven locomotion while keeping forward movement:
\begin{itemize}
  \item less high-frequency wobble,
  \item clearer lift--swing--land leg behavior,
  \item stable movement on path.
\end{itemize}

\section*{What We Changed (vs baseline \texttt{mlp\_baseline})}
\textbf{Timing and smoothness}
\begin{itemize}
  \item Phase/imitation frequency: \texttt{0.9 Hz} $\rightarrow$ \texttt{0.45 Hz}
  \item Action smoothing enabled: \texttt{action\_smooth\_alpha = 0.6}
  \item Action-rate cap: \texttt{action\_rate\_limit = 0.15}
\end{itemize}

\textbf{Contact-aware gait shaping}
\begin{itemize}
  \item Contact added to observation (\texttt{obs\_include\_contact = true})
  \item Stance penalties to reduce motion while foot is planted:
  \texttt{stance\_stability = 0.2}, \texttt{stance\_action = 0.35}
\end{itemize}

\textbf{Servo-friendly regularization}
\begin{itemize}
  \item \texttt{smoothness = 2.5}, \texttt{jerk = 0.35}, \texttt{joint\_velocity = 0.04}
\end{itemize}

\textbf{Step geometry and movement target}
\begin{itemize}
  \item Larger leg motion range:
  \texttt{abd: 35$\rightarrow$42 deg}, \texttt{flex: 60$\rightarrow$72 deg}, \texttt{max flex: 70$\rightarrow$88 deg}
  \item Target-speed shaping replaced raw velocity push:
  \texttt{target\_forward\_velocity = 0.09}, \texttt{target\_velocity\_weight = 28.0}
\end{itemize}

\section*{Results Snapshot (Evaluation)}
\begin{table}[h]
\centering
\begin{tabular}{lcc}
\toprule
Metric & Baseline MLP & MLP Run 005 \\
\midrule
Mean reward & 2817.78 & 21962.45 \\
Reward std. dev. & 3208.06 & 71.16 \\
Mean forward velocity (m/s) & 0.01266 & 0.01881 \\
Max forward velocity (m/s) & 1.0795 & 0.1750 \\
Mean energy proxy (\(\sum a^2\)) & 3.8585 & 1.0746 \\
\bottomrule
\end{tabular}
\end{table}

\textbf{Interpretation:}
\begin{itemize}
  \item Run 005 is significantly more stable (much lower reward variance).
  \item Average forward speed improved.
  \item Extreme spikes dropped; control became smoother and more servo-plausible.
  \item Energy proxy decreased, consistent with less jitter.
\end{itemize}

\section*{Visualization Upgrade}
Evaluation videos now include per-frame overlays (step, \((x,y)\), forward distance, velocity), and each episode saves a trajectory plot (\texttt{\_trajectory.png}) for quick movement diagnostics relative to the environment.

\section*{Bottom Line}
Compared with baseline MLP, \texttt{mlp\_run\_005} delivers cleaner, more insect-like, servo-realistic locomotion while preserving useful forward movement.

\end{document}

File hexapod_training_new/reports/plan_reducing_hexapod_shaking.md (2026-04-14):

# Plan: Reducing Hexapod Shaking

Shaking/jitter in the hexapod comes from fast, high-frequency changes in joint targets and torso motion. The following levers are available in the current codebase. Apply them gradually and compare eval videos.

---

## 1. Action smoothing and rate limiting (env)

These directly limit how quickly the policy can change its output.

| Lever | Current (config_terrain) | Low-shake suggestion | Effect |
|---|---|---|---|
| **action_smooth_alpha** | 0.6 | 0.72–0.78 | Blend more with previous action; reduces step-to-step jerk. |
| **action_rate_limit** | 0.15 | 0.08–0.12 | Cap max change per step; smaller cap = smoother motion. |

**Risk:** Too much smoothing or too tight a rate limit can make the robot sluggish or slow to react on rough/step terrain.

---

## 2. Reward shaping (discourage jerk and fast motion)

The reward already includes smoothness and jerk terms; increasing their weight encourages the policy to avoid shaking.

| Lever | Current | Low-shake suggestion | Effect |
|---|---|---|---|
| **smoothness_reward_weight** | 2.5 | 3.5–4.5 | Stronger penalty for large action deltas (smoother actions). |
| **jerk_penalty_weight** | 0.35 | 0.5–0.7 | Penalize acceleration of actions (less “nervous” control). |
| **joint_velocity_penalty_weight** | 0.04 | 0.06–0.10 | Discourage fast joint motion; reduces limb flutter. |
| **stability_reward_weight** | 1.0 | 1.2–1.5 | Reward staying near target height; can reduce vertical bob. |
| **stance_stability_penalty_weight** | 0.2 | 0.25–0.35 | Stronger penalty for moving when foot is planted (cleaner stance). |
| **stance_action_penalty_weight** | 0.35 | 0.4–0.5 | Same idea; less unnecessary motion during stance. |
| **tilt_penalty_weight** | 2.0 | 2.5–3.0 | Discourage torso tilt; can reduce visible wobble. |

**Risk:** Pushing these too high can favor very slow or stiff gaits; tune in small steps.

---

## 3. Low-level control (PD)

More damping at the joint level can filter out high-frequency oscillations before they become visible motion.

| Lever | Current | Low-shake suggestion | Effect |
|---|---|---|---|
| **pd_kd** | 1.0 | 1.2–1.5 | Higher damping; reduces joint overshoot and oscillation. |
| **pd_kp** | 20.0 | Keep or 18–22 | Slightly lower kp can reduce “twitchiness” if needed. |

**Risk:** Very high kd can make the robot feel sluggish or slow to track targets.

---

## 4. Control frequency (frame_skip)

| Lever | Current | Low-shake suggestion | Effect |
|---|---|---|---|
| **frame_skip** | 5 | 6–8 | Fewer policy updates per second; each action held longer, often smoother visually. |

**Risk:** Too high frame_skip can make the policy too slow to react on uneven terrain.

---

## 5. Velocity reward smoothing

| Lever | Current | Low-shake suggestion | Effect |
|---|---|---|---|
| **velocity_reward_window** | 5 | 7–9 | Velocity reward based on longer window; policy less incentivized to chase instant velocity spikes. |

**Risk:** Very long window can blur the link between action and reward; moderate increase (7–9) is a good first try.

---

## Recommended order of experiments

1. **Quick win (no new training):** Increase **action_smooth_alpha** and/or decrease **action_rate_limit** in the env; reload the same checkpoint and run eval. If the policy was already trained with some smoothing, this only affects execution and can reduce shake immediately.
2. **Config variant:** Train a new run from scratch with a “low-shake” config that:
   - Increases action_smooth_alpha (e.g. 0.75), decreases action_rate_limit (e.g. 0.10)
   - Increases smoothness_reward_weight, jerk_penalty_weight, joint_velocity_penalty_weight
   - Optionally increases pd_kd and velocity_reward_window
   - See `configs/config_terrain_low_shake.yaml`.
3. **A/B comparison:** Compare eval videos (same terrain, same episode length) for:
   - Current terrain_run vs low-shake run
   - Optionally: same policy with different inference-time smoothing (step 1).
4. **Iterate:** If still too shaky, nudge smoothness/jerk/rate limit further. If too sluggish, back off slightly.

---

## Files

- **Env/reward:** `envs/hexapod_env.py` (smoothness, jerk, joint velocity, stance, tilt, velocity window).
- **Config:** `configs/config_terrain.yaml` (current); `configs/config_terrain_low_shake.yaml` (suggested low-shake variant).
- **Camera:** `assets/hexapod_with_terrain.xml` — eval_cam position updated so the camera is a bit further back for clearer viewing.

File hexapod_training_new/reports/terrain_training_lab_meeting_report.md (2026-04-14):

# Hexapod Multi-Terrain RL: Lab Meeting Report

**Project:** Hexapod locomotion with PPO and optional sCPG  
**Focus:** Training on varied terrain (flat, rough, steps) and evaluation pipeline  
**Date:** February 2026  

---

## 1. Goal

- Train a single policy that can walk on **flat**, **rough**, and **stepped** terrain.
- Use the same reward structure and observation space as the existing flat-terrain MLP runs (e.g., mlp_run_005) so that improvements are comparable.
- Provide a clear evaluation and visualization pipeline: metrics plus videos with terrain visible and a zoomed-in camera for presentations.

---

## 2. Environment and Terrain

### 2.1 Robot and Base Setup

- **Model:** MuJoCo hexapod with 6 legs, PD-controlled joints (abd and flex per leg).
- **Task:** Circular path following (path_radius 0.5 m) with path-heading and path-proximity rewards; velocity and smoothness terms as in `config_v7_mlp_clean`-style configs.
- **Episode length:** 1000 steps (frame_skip 5).

### 2.2 Terrain Implementation

- **Asset:** `hexapod_with_terrain.xml` — same robot as `hexapod.xml`, but the floor is a **32x32 heightfield** (MuJoCo `hfield`) so we can change elevation at reset.
- **Terrain types:**
  - **Flat:** Constant zero elevation.
  - **Rough:** Random smooth noise; configurable scale and height range (`terrain_rough_scale`, `terrain_rough_min_height`, `terrain_rough_max_height`). Training uses ±2 cm; evaluation videos use ±6 cm so the terrain is clearly visible.
  - **Steps:** Stair-like profile along one axis; `terrain_step_height`, `terrain_step_length`, `terrain_num_steps` (e.g., 2 cm height, 8 cm length, 5 steps).
- **Sampling:** Each episode reset draws a terrain type. With `terrain_type: random`, the type is chosen uniformly from {flat, rough, steps}. An optional **terrain curriculum** (flat only, then flat+rough, then all three) can be enabled via config and a training callback.

### 2.3 Observation and Rewards

- Observations include joint positions, joint velocities, contact, phase, previous action, path heading error, and torso velocity (no torso quat in terrain config).
- Rewards: path heading (3.0), path proximity (2.0), target velocity (28.0), smoothness (2.5), jerk (0.35), lateral/yaw/tilt penalties, stance and idle penalties, etc., matching the flat-terrain MLP setup so the policy is incentivized for stable, directed walking on all terrains.

---

## 3. Training Setup

- **Config:** `configs/config_terrain.yaml`
- **Algorithm:** PPO (Stable-Baselines3), MLP policy [256, 256] for both policy and value.
- **Hyperparameters:** 2048 steps per env, batch 64, 10 epochs, LR 3e-4, gamma 0.99, GAE lambda 0.95, clip 0.2.
- **Training length:** 300k timesteps per run.
- **Envs:** 2 parallel envs (DummyVecEnv).
- **Checkpoints:** Every 50k steps; final model saved as `final_model.zip`.
- **Eval during training:** Every 10k steps, 5 episodes (on whatever terrain the env samples).

---

## 4. Runs

| Run | Config | Target steps | Status | Notes |
|---|---|---|---|---|
| **terrain_run_001** | config_terrain.yaml | 300,000 | Complete | 303,104 steps, 302 episodes |
| **terrain_run_002** | config_terrain.yaml | 300,000 | Complete | Same config; second replicate |

### 4.1 terrain_run_001

- **Path:** `runs/terrain_run_001/`
- **Training summary:** total_timesteps 303,104, total_episodes 302, mean_episode_length 1001.
- **Checkpoints:** progress at 28k, 57k, 86k, 114k, 143k, 172k, 200k, 229k, 258k, 286k, 303k steps; `final_model.zip` available.
- **Eval outputs:**
  - `eval/` — default eval (metrics + videos if enabled).
  - `eval_visible_terrain/` — same but with terrain heights overridden for visibility (e.g., rough ±6 cm, steps 5 cm height) and renderer recreated so the heightfield is shown; videos include a "Terrain: flat/rough/steps" overlay.

### 4.2 terrain_run_002

- **Path:** `runs/terrain_run_002/`
- **Training summary:** total_timesteps 303,104, total_episodes 302, mean_episode_length 1001 (same as run_001).
- **Eval:** Standard eval in `eval/`; can generate `eval_visible_terrain` the same way as run_001.

---

## 5. Evaluation

### 5.1 How evaluation is run

```bash
# From project root (hexapod_training_new)
python evaluate.py <path_to_model.zip> --config <config.yaml> --output-dir <dir> --num-episodes N --save-video
```

Example for terrain_run_001 with visible terrain and videos:

```bash
python evaluate.py runs/terrain_run_001/checkpoints/final_model.zip \
  --config runs/terrain_run_001/config.yaml \
  --output-dir runs/terrain_run_001/eval_visible_terrain \
  --num-episodes 6 --save-video
```

### 5.2 Terrain cycling for videos

When the env uses the terrain heightfield, the evaluator cycles terrain per episode: episode 0 → flat, 1 → rough, 2 → steps, 3 → flat, etc. Each episode’s video is labeled (e.g., "Terrain: rough") and the ground is overridden so rough/step geometry is visible in the render.

### 5.3 Metrics recorded

- **Episode-level:** total reward, episode length.
- **Step-level (aggregated):** mean/max forward velocity, mean torso height, mean energy proxy (sum of squared actions), termination reasons.
- **Output:** `evaluation_summary.yaml` in the output dir (mean_reward, std_reward, mean_length, mean_forward_velocity, max_forward_velocity, mean_torso_height, mean_energy, num_episodes, termination_counts). Exact values depend on run and number of episodes; run the command above to regenerate.

### 5.5 Results snapshot (terrain runs)

- **Training:** Both terrain_run_001 and terrain_run_002 reached ~303k steps with mean episode length 1001 (episodes run to max length; no early termination).
- **Evaluation:** Summary statistics are written to `eval/evaluation_summary.yaml` and `eval_visible_terrain/evaluation_summary.yaml`. To get a fresh snapshot for the meeting, run:
  ```bash
  python evaluate.py runs/terrain_run_001/checkpoints/final_model.zip --config runs/terrain_run_001/config.yaml --output-dir runs/terrain_run_001/eval_report --num-episodes 5 --save-video
  ```
  Then read the printed "EVALUATION SUMMARY" block or the saved `evaluation_summary.yaml`.

### 5.4 Visualization

- **Videos:** Step, (x, y), forward distance, forward velocity, and terrain label overlaid on each frame. Saved under `<output-dir>/videos/` (e.g., `episode_1.mp4`).
- **Trajectory plots:** For each episode, `episode_N_trajectory.png` with (x, y) trajectory and forward distance/velocity vs step.
- **Camera:** The terrain asset defines an `eval_cam` camera (targetbody on torso, close offset, fovy 42°) used automatically during `render()` so evaluation videos are zoomed in for lab meetings.

---

## 6. Implementation Notes (for reproducibility)

- **Terrain in reset:** In `HexapodEnv.reset()`, when terrain is enabled, we compute heights with `_generate_terrain_heights(terrain_kind)`, write to `model.hfield_data`, and set `_terrain_changed = True`.
- **Rendering:** When `_terrain_changed` is True, the next `render()` call closes and recreates the MuJoCo renderer so the updated heightfield is drawn. The same render path uses `eval_cam` when present (terrain XML).
- **Config:** All terrain-related options (terrain_type, rough/step parameters, terrain_curriculum, terrain_curriculum_stages) are in `configs/config_terrain.yaml` and passed through `make_hexapod_env()`.

---

## 7. Summary for the lab meeting

- **What we did:** Added a heightfield-based terrain system (flat / rough / steps) and trained two full runs (terrain_run_001, terrain_run_002) with 300k steps each. The policy is evaluated across all three terrains with metrics and zoomed-in, terrain-labeled videos.
- **Where to look:** `runs/terrain_run_001/` and `runs/terrain_run_002/` for training summaries and checkpoints; `eval_visible_terrain/videos/` for presentation-ready clips; `evaluation_summary.yaml` in each eval dir for numeric results.
- **Next steps (optional):** Enable terrain curriculum, tune rough/step difficulty, or compare terrain policy vs flat-only policy on a fixed test set of terrains.

---

## 8. File reference

| Item | Path |
|---|---|
| Terrain config | `configs/config_terrain.yaml` |
| Terrain XML | `assets/hexapod_with_terrain.xml` |
| Env + terrain logic | `envs/hexapod_env.py` |
| Training script | `train.py` |
| Evaluation script | `evaluate.py` |
| Run 001 | `runs/terrain_run_001/` |
| Run 002 | `runs/terrain_run_002/` |
| This report | `reports/terrain_training_lab_meeting_report.md` |

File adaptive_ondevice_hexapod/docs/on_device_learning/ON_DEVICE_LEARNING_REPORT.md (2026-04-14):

# On-Device Learning Report (Whiteboard Pipeline)

This report translates the whiteboard nodes into a practical pipeline for learning locomotion directly on the robot (Teensy + servo stack), with PPO-style adaptation and safety-first execution.

## 1) What the board is telling us

Interpreting the whiteboard nodes:
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

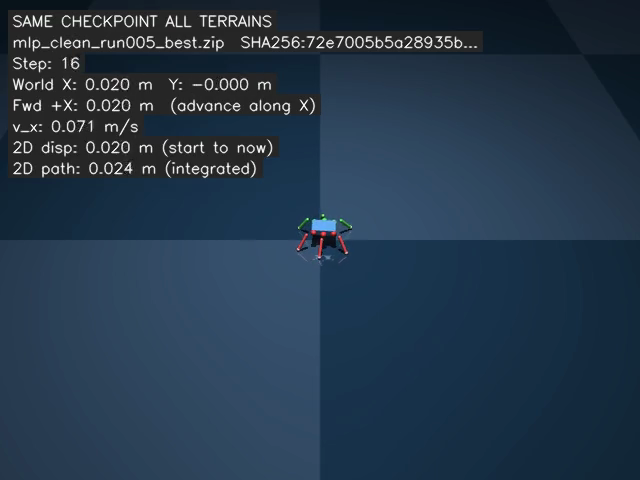
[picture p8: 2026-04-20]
final_report/ppo_mlp_run005_episode1_frame.png

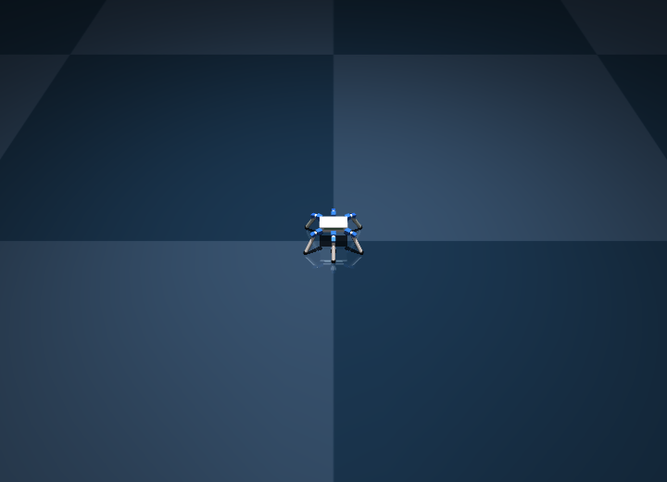
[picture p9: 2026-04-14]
e90_repo/assets/hexapod_mujoco_preview.png

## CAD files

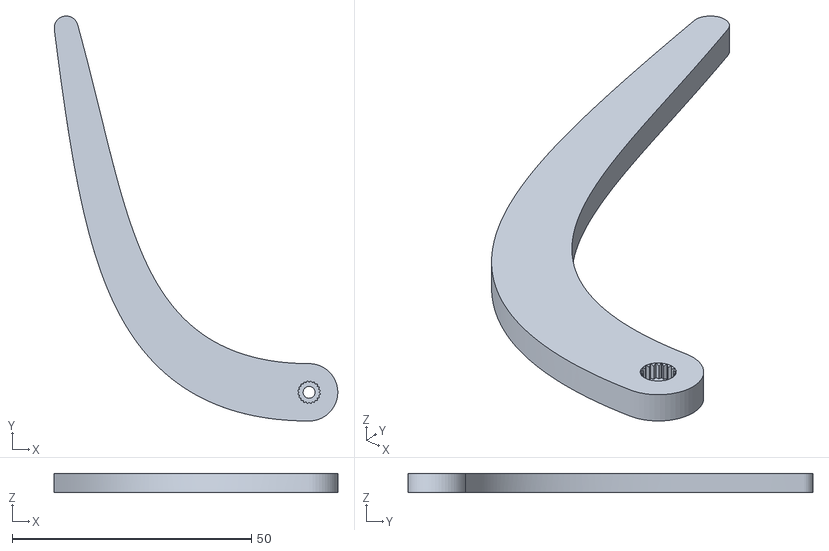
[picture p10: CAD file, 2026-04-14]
e90_repo/assets/meshes/SG90.stl
59.3 x 84.7 x 4.00

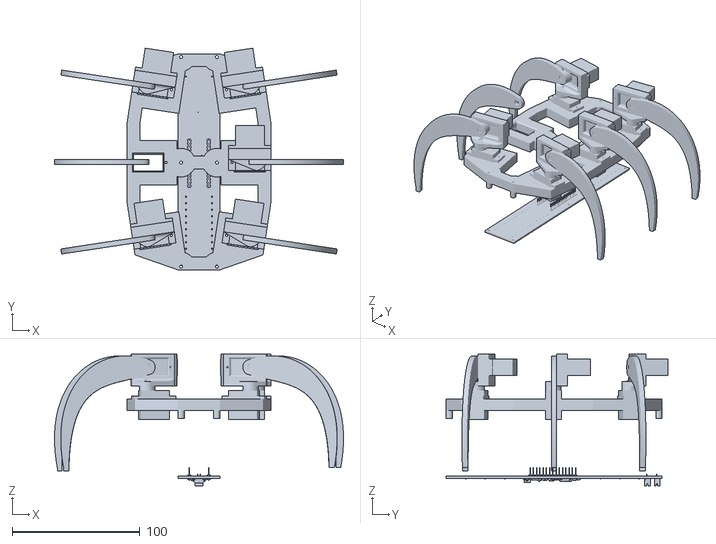
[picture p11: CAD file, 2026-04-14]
e90_repo/assets/meshes/hexapod.stl
226.0 x 173.3 x 103.2

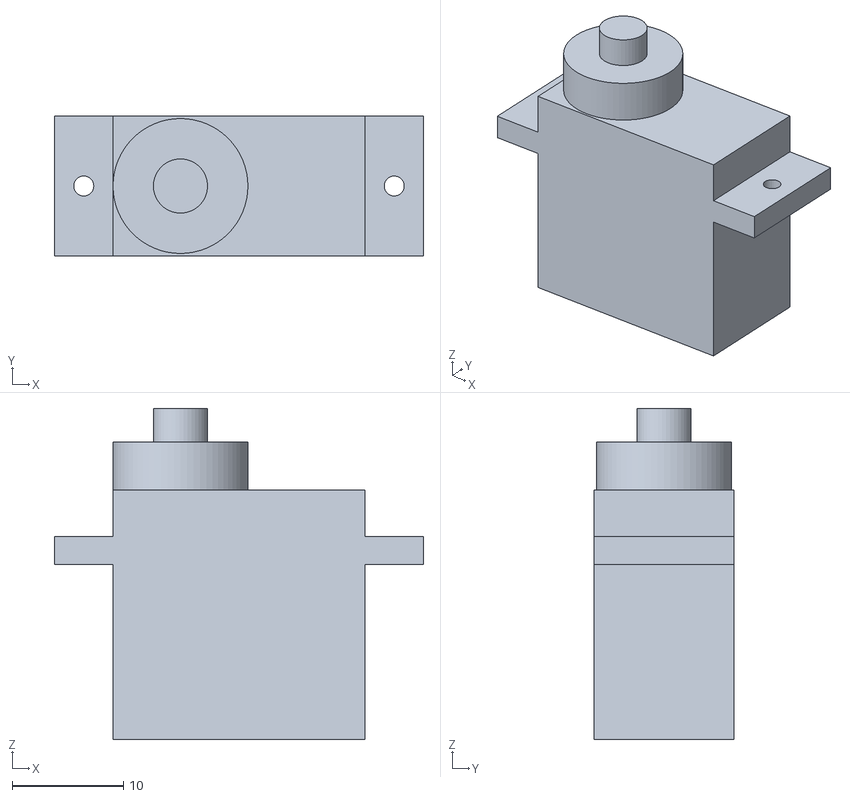
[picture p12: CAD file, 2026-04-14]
hexapod_training_new/assets/meshes/Servo Motor.stl
33.1 x 12.6 x 29.7

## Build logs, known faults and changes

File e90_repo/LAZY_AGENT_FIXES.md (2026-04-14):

# Why the Robot Moves Once Then Stops (Lazy Agent) and How to Fix It

## What’s going on

The hexapod is hitting the classic **“Lazy Agent”** (or **local minimum**) in RL locomotion: it learns that **standing still is safer than walking**.

- **Risk:** When it explores by moving, it often tilts or falls.
- **Punishment:** Episodes end on fall/tilt/leg-up (`_check_termination` in `envs/hexapod_env.py`), so it gets a big negative signal and no more rewards.
- **Reward:** With `survival_bonus: 0` you already removed “reward for existing.” But velocity reward is only positive when moving; when still, reward is small or zero, and there was no explicit penalty for standing still.
- **Result:** The policy prefers “move a little once, then freeze” over “keep walking,” because continuing to move increases the chance of crossing a termination condition.

So the robot isn’t broken; it’s exploiting the reward and termination design.

## How this matches your code

1. **Termination** (`_check_termination`): Episode ends on `torso_pos[2] < min_torso_height`, tilt `> max_torso_tilt`, or flexion `> max_flexion_angle`. So “tilting = death” and the agent never gets to learn recovery.
2. **Reward** (`_compute_reward`): You use `forward_velocity_weight * max(0, avg_forward_velocity)` and no survival bonus. There was no penalty for near-zero velocity (`idle_velocity_penalty_weight` was 0 in your run).
3. **Reset** (`reset`): Joint noise was small (0.05 rad) and no initial forward velocity, so the robot always started from a near standstill.
4. **No lateral penalty:** Only backward velocity was penalized; lateral drift wasn’t, so “walk straight” wasn’t strongly encouraged.

## What was implemented (four strategies)

### 1. Softer “fear of falling” (termination logic)

- **New env options:** `terminate_on_fall`, `terminate_on_tilt`, `terminate_on_leg_up` (all default `True`).
- **`terminate_on_fall: false`:** Episode no longer ends when `torso_pos[2] < min_torso_height`. The robot can stay on the ground and still get rewards for forward velocity if it moves (e.g. writhe and scoot).
- **`fall_penalty_weight`:** When not terminating on fall, the env still adds a per-step penalty when `torso_pos[2] < min_torso_height`, so the agent learns to avoid being down without the episode ending.

This reduces the incentive to “do nothing to avoid termination.”

### 2. “Stand still” penalty and lateral drift

- **`idle_velocity_penalty_weight`:** Already in the env; now used in the anti-lazy config. If `|forward_velocity| < idle_velocity_threshold`, the robot gets a penalty each step (e.g. 0.5).
- **`lateral_velocity_penalty_weight`:** New. Penalizes `|torso_lin_vel[1]|` so going straight is preferred.

Together, standing still becomes costly and walking straight is rewarded.

### 3. Initialize in motion (reset)

- **`reset_joint_noise_scale`:** Default 0.05; can be increased (e.g. 0.25) so the robot starts slightly off-balance and must react.
- **`reset_initial_forward_velocity`:** New. Sets `qvel[0]` at reset (e.g. 0.15) so the robot starts with a small forward shove and must use its legs to maintain balance and motion.

So the agent no longer learns only from a dead standstill.

### 4. Phase-based / imitation (already in the codebase)

- **`obs_include_phase`**, **`imitation_weight`**, **`imitation_action_mix`**, **`_tripod_reference_action`** already implement a phase signal and optional tripod imitation. You can enable these in config for “training wheels” and then reduce or turn them off later.

## Config to try first: anti-lazy

**`configs/config_v7_anti_lazy.yaml`** applies the above:

- `terminate_on_fall: false`, `fall_penalty_weight: 2.0`
- `idle_velocity_penalty_weight: 0.5`, `lateral_velocity_penalty_weight: 1.0`
- `reset_joint_noise_scale: 0.25`, `reset_initial_forward_velocity: 0.15`
- Same PD and velocity-only reward as your v5-style run (e.g. `forward_velocity_weight: 50`).

Train with:

```bash
python train.py --config configs/config_v7_anti_lazy.yaml --version 2 --output-dir runs/anti_lazy_001
```

If the robot still freezes after a few steps, try:

- Increasing `idle_velocity_penalty_weight` (e.g. 1.0).
- Enabling phase-based imitation: set `imitation_weight` and/or `imitation_action_mix` in the same config so the policy gets a strong tripod signal early, then decay it in a later run.

## References (online)

- Reward shaping and “lazy” local optima in locomotion: agents can exploit reward structure so that inaction is preferred (e.g. Isaac Lab / JetBot reward exploration docs, barrier-style reward shaping for locomotion).
- Letting the robot recover instead of terminating on fall: research on fall recovery and time-varying rewards suggests not always ending the episode on first fall so the agent can learn to recover and keep moving; your `terminate_on_fall: false` + `fall_penalty_weight` follows that idea.
- Phase / clock input for periodic gaits: adding a phase (or imitation) signal is a standard way to help PPO find a rhythm (e.g. tripod) instead of discovering it from scratch; your code already supports this.

---

**Summary:** The robot “moves once then stops” because the current reward and termination make standing still a relatively safe, high-return strategy. The env now supports optional no-termination-on-fall with a fall penalty, idle and lateral penalties, and reset-in-motion. Use `config_v7_anti_lazy.yaml` first; if needed, add phase-based imitation next.

## Post-run: anti_lazy_v7_1M (still not moving)

After 1M steps, mean_episode_length stayed ~35. Cause: **tilt death trap** — with only `terminate_on_tilt: true` left, the robot hit 45 deg tilt in ~35 steps and died; the policy learned to avoid motion. Fix: set **`terminate_on_tilt: false`** and **`tilt_penalty_weight: 2.0`** so episodes run to 1000 steps and the agent pays for tilt per step instead of terminating. Re-train with updated config_v7_anti_lazy.yaml.

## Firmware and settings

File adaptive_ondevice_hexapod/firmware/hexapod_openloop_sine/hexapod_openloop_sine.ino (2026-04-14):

/*
 * Open-loop sinusoidal tripod gait (no IMU) — same phase/rest/shift structure as
 * hexapod_brain_roadmap copy/ode_optimization_no_imu/hexapod_no_imu_optimization.py
 *
 * Optimizer outputs angles in degrees; jointToUs() applies those as *microsecond
 * offsets* from servoCenter. ABD_CMD_PER_DEG / FLX_CMD_PER_DEG must stay small enough
 * that (deg × scale) stays within ~±400–500 µs typical travel — not ~42 µs/deg on flex.
 *
 * Leg order: FL, FR, ML, MR, RL, RR (Maestro channels 0..11, abd then flx per leg).
 * Tripod A: FL, MR, RL (phase 0); Tripod B: FR, ML, RR (phase pi).
 */

#include <math.h>

#include "optimized_gait_params.h"

#define maestroSerial Serial1

#ifndef PI
#define PI 3.14159265358979323846
#endif

enum ServoID {
  FL_ABD = 0, FL_FLX = 1,
  FR_ABD = 2, FR_FLX = 3,
  ML_ABD = 4, ML_FLX = 5,
  MR_ABD = 6, MR_FLX = 7,
  RL_ABD = 8, RL_FLX = 9,
  RR_ABD = 10, RR_FLX = 11
};

const int NUM_SERVOS = 12;

int servoCenter[NUM_SERVOS] = {
  1500, 1500,
  1500, 1500,
  1500, 1500,
  1500, 1500,
  1500, 1500,
  1500, 1500
};

// v2 mirror: left (+1,-1), right (-1,+1). Using (-1,+1) on *every* channel removes
// L/R mirroring and often looks "twisted" even if a single-leg test looked backward.
// Fix left issues with the multipliers below (±1 only). Try FLX first, then ABD, then both.
static const int L_ABD = +1;
static const int L_FLX = -1;
static const int R_ABD = -1;
static const int R_FLX = +1;
static const int LEFT_FLIP_ABD = +1;  // -1 to invert abduction on FL, ML, RL only
static const int LEFT_FLIP_FLX = +1;  // -1 to invert flex on FL, ML, RL only

int servoDir[NUM_SERVOS] = {
  L_ABD * LEFT_FLIP_ABD, L_FLX * LEFT_FLIP_FLX,
  R_ABD, R_FLX,
  L_ABD * LEFT_FLIP_ABD, L_FLX * LEFT_FLIP_FLX,
  R_ABD, R_FLX,
  L_ABD * LEFT_FLIP_ABD, L_FLX * LEFT_FLIP_FLX,
  R_ABD, R_FLX,
};

// 1: Serial @115200 — pulse samples + clip counts every ~500 ms (disable for silent runs).
#ifndef OPENLOOP_DIAG_SERIAL
#define OPENLOOP_DIAG_SERIAL 1
#endif
#ifndef OPENLOOP_CLIP_REPORT
#define OPENLOOP_CLIP_REPORT OPENLOOP_DIAG_SERIAL
#endif
// Pause (µs) after each Maestro Set Target; helps some serial links.
#ifndef MAESTRO_CMD_GAP_US
#define MAESTRO_CMD_GAP_US 120
#endif

int currentUs[NUM_SERVOS];

const int MIN_US = 600;
const int MAX_US = 2400;

// ms between gait updates (same order of magnitude as v2 INTERP_DELAY)
const unsigned INTERP_DELAY_MS = 10;

// Degrees → µs offset at servoCenter (keep modest so jointCommand stays ~hundreds of µs).
const float ABD_CMD_PER_DEG = 8.0f;
const float FLX_CMD_PER_DEG = 6.0f;

// Limits on abstract *joint commands* (µs offset before servoDir). Tight FLX max avoids
// huge excursions when scale × degrees was miscalibrated.
const int ABD_CMD_MIN = -400;
const int ABD_CMD_MAX = 400;
const int FLX_CMD_MIN = -400;
const int FLX_CMD_MAX = 480;

// Ramp 0 → target frequency over this many ms at boot (smoother bring-up).
const unsigned long FREQ_RAMP_MS = 4000;
// If > 0, caps gait Hz after ramp: min(OPT_FREQUENCY_HZ, cap). Use 1.0f for calmer bench;0 for full OPT.
static const float BENCH_FREQ_CAP_HZ = 1.0f;

// Tripod phase offset per leg index: FL, FR, ML, MR, RL, RR
const float TRIPOD_OFFSET_RAD[6] = {
  0.f,
  (float)PI,
  (float)PI,
  0.f,
  0.f,
  (float)PI
};

unsigned long lastTickMs = 0;
double phase = 0.0;
unsigned long bootMs = 0;

#if OPENLOOP_CLIP_REPORT
static uint16_t g_clipAbdCmd;
static uint16_t g_clipFlxCmd;
static uint16_t g_clipUs;
#endif

void setMaestroTarget(uint8_t channel, uint16_t targetUs) {
  uint16_t target = targetUs * 4;
  maestroSerial.write(0x84);
  maestroSerial.write(channel);
  maestroSerial.write(target & 0x7F);
  maestroSerial.write((target >> 7) & 0x7F);
}

int clampUs(int us) {
  if (us < MIN_US) return MIN_US;
  if (us > MAX_US) return MAX_US;
  return us;
}

int jointToUs(uint8_t servo, int jointCommand) {
  return clampUs(servoCenter[servo] + servoDir[servo] * jointCommand);
}

/** Like jointToUs; if clipCount non-null, increments when output hits MIN_US/MAX_US. */
int jointToUsClip(uint8_t servo, int jointCommand, uint16_t* clipCount) {
  int raw = servoCenter[servo] + servoDir[servo] * jointCommand;
  int us = clampUs(raw);
  if (clipCount != nullptr && us != raw) {
    (*clipCount)++;
  }
  return us;
}

int clampAbdCmd(int c) {
  if (c < ABD_CMD_MIN) return ABD_CMD_MIN;
  if (c > ABD_CMD_MAX) return ABD_CMD_MAX;
  return c;
}

int clampFlxCmd(int c) {
  if (c < FLX_CMD_MIN) return FLX_CMD_MIN;
  if (c > FLX_CMD_MAX) return FLX_CMD_MAX;
  return c;
}

void writeAll() {
  for (int i = 0; i < NUM_SERVOS; i++) {
    setMaestroTarget(i, currentUs[i]);
#if MAESTRO_CMD_GAP_US > 0
    delayMicroseconds(MAESTRO_CMD_GAP_US);
#endif
  }
}

void buildPose(
  int targetUs[NUM_SERVOS],
  int fl_abd, int fl_flx,
  int fr_abd, int fr_flx,
  int ml_abd, int ml_flx,
  int mr_abd, int mr_flx,
  int rl_abd, int rl_flx,
  int rr_abd, int rr_flx,
  uint16_t* usClipCount
) {
  targetUs[FL_ABD] = jointToUsClip(FL_ABD, fl_abd, usClipCount);
  targetUs[FL_FLX] = jointToUsClip(FL_FLX, fl_flx, usClipCount);
  targetUs[FR_ABD] = jointToUsClip(FR_ABD, fr_abd, usClipCount);
  targetUs[FR_FLX] = jointToUsClip(FR_FLX, fr_flx, usClipCount);
  targetUs[ML_ABD] = jointToUsClip(ML_ABD, ml_abd, usClipCount);
  targetUs[ML_FLX] = jointToUsClip(ML_FLX, ml_flx, usClipCount);
  targetUs[MR_ABD] = jointToUsClip(MR_ABD, mr_abd, usClipCount);
  targetUs[MR_FLX] = jointToUsClip(MR_FLX, mr_flx, usClipCount);
  targetUs[RL_ABD] = jointToUsClip(RL_ABD, rl_abd, usClipCount);
  targetUs[RL_FLX] = jointToUsClip(RL_FLX, rl_flx, usClipCount);
  targetUs[RR_ABD] = jointToUsClip(RR_ABD, rr_abd, usClipCount);
  targetUs[RR_FLX] = jointToUsClip(RR_FLX, rr_flx, usClipCount);
}

static float gaitFrequencyTargetHz() {
  float f = OPT_FREQUENCY_HZ;
  if (BENCH_FREQ_CAP_HZ > 0.f && f > BENCH_FREQ_CAP_HZ) {
    f = BENCH_FREQ_CAP_HZ;
  }
  return f;
}

/** Effective frequency during optional startup ramp */
float frequencyNow(unsigned long nowMs) {
  float target = gaitFrequencyTargetHz();
  if (FREQ_RAMP_MS == 0) {
    return target;
  }
  unsigned long t = nowMs - bootMs;
  if (t >= FREQ_RAMP_MS) {
    return target;
  }
  return target * (float)t / (float)FREQ_RAMP_MS;
}

void applySineGaitTick(float dt) {
  float f = frequencyNow(millis());
  phase += 2.0 * PI * (double)f * (double)dt;
  while (phase >= 2.0 * PI) phase -= 2.0 * PI;
  while (phase < 0.0) phase += 2.0 * PI;

  int abdCmd[6];
  int flxCmd[6];

  for (int i = 0; i < 6; i++) {
    float legBase = (float)phase + TRIPOD_OFFSET_RAD[i];
    float abdPh = legBase + OPT_ABD_SHIFT_DEG[i] * (float)(PI / 180.0);
    float flxPh = legBase + OPT_FLX_SHIFT_DEG[i] * (float)(PI / 180.0);

    float abdDeg = OPT_ABD_REST_DEG[i] + OPT_ABD_AMP_DEG[i] * sinf(abdPh);
    float flxDeg = OPT_FLX_REST_DEG[i] + OPT_FLX_AMP_DEG[i] * sinf(flxPh);

    // Swing lift (matches Python LIFT_SWING_DEG_PEAK): pull foot up when sin(abd)>0 — tune sign on hardware if needed
    float sinAbd = sinf(abdPh);
    float liftBlend = (sinAbd > 0.f) ? sinAbd : 0.f;
    flxDeg -= OPT_LIFT_SWING_DEG_PEAK * liftBlend;

    int jAbd = (int)lroundf(abdDeg * ABD_CMD_PER_DEG);
    int jFlx = (int)lroundf(flxDeg * FLX_CMD_PER_DEG);
    abdCmd[i] = clampAbdCmd(jAbd);
    flxCmd[i] = clampFlxCmd(jFlx);
#if OPENLOOP_CLIP_REPORT
    if (abdCmd[i] != jAbd) {
      g_clipAbdCmd++;
    }
    if (flxCmd[i] != jFlx) {
      g_clipFlxCmd++;
    }
#endif
  }

  uint16_t usClips = 0;
  int target[NUM_SERVOS];
  buildPose(
    target,
    abdCmd[0], flxCmd[0],
    abdCmd[1], flxCmd[1],
    abdCmd[2], flxCmd[2],
    abdCmd[3], flxCmd[3],
    abdCmd[4], flxCmd[4],
    abdCmd[5], flxCmd[5],
    OPENLOOP_CLIP_REPORT ? &usClips : nullptr
  );

#if OPENLOOP_CLIP_REPORT
  g_clipUs += usClips;
#endif

  for (int s = 0; s < NUM_SERVOS; s++) {
    currentUs[s] = target[s];
  }
#if OPENLOOP_DIAG_SERIAL
  static unsigned long _diagMs = 0;
  unsigned long _now = millis();
  if (_now - _diagMs >= 500) {
    _diagMs = _now;
    Serial.print(F("us L: FL "));
    Serial.print(target[FL_ABD]);
    Serial.print(F(","));
    Serial.print(target[FL_FLX]);
    Serial.print(F(" ML "));
    Serial.print(target[ML_ABD]);
    Serial.print(F(","));
    Serial.print(target[ML_FLX]);
    Serial.print(F(" RL "));
    Serial.print(target[RL_ABD]);
    Serial.print(F(","));
    Serial.print(target[RL_FLX]);
    Serial.print(F(" | R: FR "));
    Serial.print(target[FR_ABD]);
    Serial.print(F(","));
    Serial.print(target[FR_FLX]);
#if OPENLOOP_CLIP_REPORT
    Serial.print(F(" | clips(cmd abd,flx / us)="));
    Serial.print(g_clipAbdCmd);
    Serial.print(F(","));
    Serial.print(g_clipFlxCmd);
    Serial.print(F("/"));
    Serial.print(g_clipUs);
    g_clipAbdCmd = 0;
    g_clipFlxCmd = 0;
    g_clipUs = 0;
#endif
    Serial.println();
  }
#endif
  writeAll();
}

void setup() {
#if OPENLOOP_DIAG_SERIAL
  Serial.begin(115200);
  delay(500);
#endif
  bootMs = millis();
  lastTickMs = bootMs;

  maestroSerial.begin(9600);
  delay(1500);

  maestroSerial.write(0xAA);
  delay(100);

  for (int i = 0; i < 3; i++) {
    maestroSerial.write(0xA1);
    delay(50);
  }

  for (int i = 0; i < NUM_SERVOS; i++) {
    currentUs[i] = clampUs(servoCenter[i]);
  }
  writeAll();
  delay(500);

  // Brief hold at rest pose (sin t=0) before continuous motion
  applySineGaitTick(0.f);
  delay(300);
}

void loop() {
  unsigned long now = millis();
  unsigned long dtMs = now - lastTickMs;
  if (dtMs < INTERP_DELAY_MS) return;

  lastTickMs = now;
  float dt = (float)dtMs / 1000.0f;
  if (dt > 0.05f) dt = 0.05f;

  applySineGaitTick(dt);
}

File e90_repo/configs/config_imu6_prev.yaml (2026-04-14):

# IMU + previous action + phase clock (20D): fixes "robot does not move" vs raw low-shake config.
#
# Root cause: smoothness (4) + jerk + stance penalties + high action_smooth_alpha fought any
# oscillating gait; imitation toward a time-varying tripod reference made that worse. Forward
# velocity had no direct weight (only Gaussian target).
#
# Changes: turn off imitation, slash smoothness/jerk/stance, lower action smoothing, add
# forward_velocity_weight, add sin/cos phase (available on real robot as a timer), slightly
# higher entropy. Retrain from scratch.

env:
  observation_mode: imu6_prev
  imu_noise_std_accel: 0.02
  imu_noise_std_gyro: 0.005
  action_rate_limit: 0.15
  action_scale_abd_deg: 42.0
  action_scale_flex_deg: 72.0
  action_smooth_alpha: 0.2
  action_use_joint_limits: false
  action_warmup_steps: 0
  frame_skip: 6
  max_episode_steps: 1000
  max_flexion_angle: 88
  max_torso_tilt: 45
  min_torso_height: 0.05
  obs_include_contact: false
  obs_include_joint_pos: false
  obs_include_joint_vel: false
  obs_include_path_heading_error: false
  obs_include_phase: true
  obs_include_prev_action: false
  obs_include_torso_quat: false
  obs_include_torso_vel: false
  obs_phase_frequency_hz: 0.45
  obs_use_sensors: false
  path_type: null
  pd_kd: 1.25
  pd_kp: 20.0
  pd_steps_per_action: 10
  reset_initial_forward_velocity: 0.06
  reset_joint_noise_scale: 0.25
  target_torso_height: 0.1
  terminate_on_fall: false
  terminate_on_leg_up: false
  terminate_on_tilt: false
  use_pd_control: true
evaluation:
  num_episodes: 5
  render: false
  save_video: false
  video_dir: videos
ppo:
  batch_size: 64
  clip_range: 0.2
  ent_coef: 0.06
  gae_lambda: 0.95
  gamma: 0.99
  learning_rate: 0.0003
  max_grad_norm: 0.5
  n_epochs: 10
  n_steps: 2048
  policy_kwargs:
    net_arch:
      pi: [256, 256]
      vf: [256, 256]
  use_mlp_policy: true
  vf_coef: 0.5
reward:
  backward_penalty_weight: 0.0
  fall_penalty_weight: 2.0
  forward_distance_weight: 0.0
  forward_velocity_weight: 12.0
  height_penalty_threshold: 0.06
  height_penalty_weight: 0.0
  idle_velocity_penalty_weight: 2.0
  idle_velocity_threshold: 0.02
  imitation_abd_sign: 1.0
  imitation_action_mix: 0.0
  imitation_amp_abd: 0.25
  imitation_amp_flex: 0.4
  imitation_flex_sign: -1.0
  imitation_frequency_hz: 0.45
  imitation_weight: 0.0
  jerk_penalty_weight: 0.08
  joint_velocity_penalty_weight: 0.03
  lateral_velocity_penalty_weight: 1.0
  path_heading_reward_weight: 0.0
  path_proximity_reward_weight: 0.0
  path_proximity_tolerance: 0.1
  smoothness_reward_weight: 0.5
  stability_reward_weight: 1.0
  stall_penalty_threshold: 0.05
  stall_penalty_weight: 0.5
  stance_action_penalty_weight: 0.05
  stance_stability_penalty_weight: 0.05
  survival_bonus: 0.0
  target_forward_velocity: 0.09
  target_velocity_scale: 0.12
  target_velocity_weight: 22.0
  tilt_penalty_weight: 2.0
  velocity_reward_window: 7
  yaw_rate_penalty_weight: 1.0
scpg:
  neurons_per_oscillator: 32
  num_timesteps: 10
  tau_mem: 20.0
  tau_syn: 10.0
  use_tripod_gait: true
training:
  checkpoint_dir: checkpoints
  eval_freq: 10000
  imitation_action_mix_decay_steps: 0
  imitation_action_mix_eval: 0.0
  imitation_action_mix_end: 0.0
  imitation_action_mix_start: 0.0
  log_dir: logs
  log_interval: 10
  n_eval_episodes: 3
  save_freq: 50000
  seed: 43
  total_timesteps: 300000

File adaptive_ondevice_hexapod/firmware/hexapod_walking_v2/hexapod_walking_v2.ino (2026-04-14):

/*
================================================================================
12-DOF HEXAPOD TRIPOD GAIT CONTROLLER  —  v2
================================================================================

Changes from v1:
  1. Body rides higher at rest  (START_FLEX raised from 1100 → 1400)
  2. Swing phase now truly LIFTS the leg off the ground (new LIFT_FLEX = -300)
  3. Gait restructured into   lift → swing → plant   sub-phases
     so the foot clears the ground, travels forward in the air,
     then plants before the stance legs push.
  4. Push phase slightly reduced (1850 → 1650) to avoid bottoming out
     at the higher ride height.

Everything else (channel map, Maestro protocol, mirroring, baseline
offsets) is unchanged from v1.

================================================================================
*/

#define maestroSerial Serial1

// ============================================================================
// ENUM: SERVO IDs
// ============================================================================

enum ServoID {
  FL_ABD = 0, FL_FLX = 1,
  FR_ABD = 2, FR_FLX = 3,
  ML_ABD = 4, ML_FLX = 5,
  MR_ABD = 6, MR_FLX = 7,
  RL_ABD = 8, RL_FLX = 9,
  RR_ABD = 10, RR_FLX = 11
};

const int NUM_SERVOS = 12;

// ============================================================================
// SERVO CENTER CALIBRATION  (microseconds)
// ============================================================================

int servoCenter[NUM_SERVOS] = {
  1500, 1500,   // FL_ABD, FL_FLX
  1500, 1500,   // FR_ABD, FR_FLX
  1500, 1500,   // ML_ABD, ML_FLX
  1500, 1500,   // MR_ABD, MR_FLX
  1500, 1500,   // RL_ABD, RL_FLX
  1500, 1500    // RR_ABD, RR_FLX
};

// ============================================================================
// SERVO DIRECTION CALIBRATION
// ============================================================================

int servoDir[NUM_SERVOS] = {
  +1, -1,   // FL_ABD, FL_FLX
  -1, +1,   // FR_ABD, FR_FLX
  +1, -1,   // ML_ABD, ML_FLX
  -1, +1,   // MR_ABD, MR_FLX
  +1, -1,   // RL_ABD, RL_FLX
  -1, +1    // RR_ABD, RR_FLX
};

// ============================================================================
// CURRENT SERVO COMMANDS
// ============================================================================

int currentUs[NUM_SERVOS];

// ============================================================================
// BASELINE ABDUCTION OFFSETS  (standing geometry — unchanged from v1)
// ============================================================================

const int FRONT_ABD_OFFSET = 180;
const int MID_ABD_OFFSET   = 0;
const int REAR_ABD_OFFSET  = -180;

// ============================================================================
// DYNAMIC ABDUCTION GAIT AMPLITUDES
// ----------------------------------------------------------------------------
// Slightly increased to take advantage of the fact that feet now truly
// clear the ground during swing.
// ============================================================================

const int FRONT_SWING_ABD = 110;    // was 90  — longer stride now that feet lift
const int FRONT_PUSH_ABD  = -110;   // was -90

const int MID_SWING_ABD   = 85;     // was 70
const int MID_PUSH_ABD    = -85;    // was -70

const int REAR_SWING_ABD  = 110;    // was 90
const int REAR_PUSH_ABD   = -110;   // was -90

// ============================================================================
// FLEXION / EXTENSION GAIT TUNING
// ----------------------------------------------------------------------------
// Positive FLX = more DOWN.
//
// v2 changes:
//   START_FLEX   1100 → 1400   Higher resting body height.
//   PUSH_FLEX    1850 → 1650   Strong push without bottoming out.
//   LIFT_FLEX    (new) -120    Slightly reduced lift versus original -300.
//   PLANT_FLEX   (new) 1400    Re-plants to normal stance height.
//
// The old RELEASE_FLEX (700) only "lightened" the leg — it did not
// lift the foot, so the robot dragged.  LIFT_FLEX fixes that.
// ============================================================================

const int START_FLEX = 1400;    // neutral standing — body is higher now
const int PUSH_FLEX  = 1650;    // stance legs push hard (near original behavior)
const int LIFT_FLEX  = -120;    // swing legs lift less, but still clear ground
const int PLANT_FLEX = 1400;    // same as START — foot re-plants at ride height

// ============================================================================
// GAIT SPEED / SMOOTHING
// ----------------------------------------------------------------------------
// Several step counts are used for different sub-phases so timing
// can be tuned independently.
// ============================================================================

const int INTERP_DELAY = 10;    // ms per interpolation step  (unchanged)

const int LIFT_STEPS   = 10;    // fast lift so foot clears quickly
const int SWING_STEPS  = 16;    // moderate speed forward swing
const int PLANT_STEPS  = 8;     // quick replant
const int PUSH_STEPS   = 16;    // matches swing so stride is symmetric
const int MID_STEPS    = 12;    // transition back to neutral

// ============================================================================
// SERVO SAFETY CLAMP
// ============================================================================

const int MIN_US = 600;
const int MAX_US = 2400;

// ============================================================================
// LOW-LEVEL MAESTRO WRITE
// ============================================================================

void setMaestroTarget(uint8_t channel, uint16_t targetUs) {
  uint16_t target = targetUs * 4;

  maestroSerial.write(0x84);
  maestroSerial.write(channel);
  maestroSerial.write(target & 0x7F);
  maestroSerial.write((target >> 7) & 0x7F);
}

// ============================================================================
// CLAMP TO SAFE RANGE
// ============================================================================

int clampUs(int us) {
  if (us < MIN_US) return MIN_US;
  if (us > MAX_US) return MAX_US;
  return us;
}

// ============================================================================
// ABSTRACT JOINT COMMAND → REAL SERVO PULSE
// ============================================================================

int jointToUs(uint8_t servo, int jointCommand) {
  return clampUs(servoCenter[servo] + servoDir[servo] * jointCommand);
}

// ============================================================================
// WRITE CURRENT POSE TO ALL SERVOS
// ============================================================================

void writeAll() {
  for (int i = 0; i < NUM_SERVOS; i++) {
    setMaestroTarget(i, currentUs[i]);
  }
}

// ============================================================================
// SMOOTH INTERPOLATED MOVE
// ============================================================================
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

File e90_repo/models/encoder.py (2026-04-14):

"""
Spike Encoding and Decoding Modules

This module provides encoding schemes to convert continuous observations
to spike trains and decoding schemes to convert spike outputs to
continuous action values.
"""

import torch
import torch.nn as nn
import numpy as np
from typing import Tuple, Optional, Dict, Any, List
from gymnasium import spaces

from stable_baselines3.common.policies import ActorCriticPolicy
from stable_baselines3.common.torch_layers import BaseFeaturesExtractor

from .scpg import SpikingCPG, CPGWithValueHead, SpikingCPGTripod, CPGWithValueHeadTripod


class SpikeEncoder(nn.Module):
    """
    Encode continuous observations into spike trains.
    
    Supports multiple encoding schemes:
    - Rate coding: Higher values -> higher firing rates
    - Latency coding: Higher values -> earlier spike times
    - Population coding: Multiple neurons per input dimension
    """
    
    def __init__(
        self,
        input_size: int,
        encoding_type: str = "rate",
        num_timesteps: int = 10,
        population_size: int = 1,
        max_rate: float = 100.0,  # Hz
        dt: float = 1.0,  # ms
    ):
        super().__init__()
        self.input_size = input_size
        self.encoding_type = encoding_type
        self.num_timesteps = num_timesteps
        self.population_size = population_size
        self.max_rate = max_rate
        self.dt = dt
        
        # For population coding
        if encoding_type == "population":
            # Gaussian receptive fields
            self.centers = nn.Parameter(
                torch.linspace(-1, 1, population_size).unsqueeze(0).repeat(input_size, 1),
                requires_grad=False
            )
            self.sigma = 2.0 / population_size
        
        # Learnable gain for rate coding
        self.gain = nn.Parameter(torch.ones(input_size))
        self.bias = nn.Parameter(torch.zeros(input_size))
    
    def forward(self, x: torch.Tensor) -> torch.Tensor:
        """
        Encode continuous values to spike trains.
        
        Args:
            x: Input tensor (batch, input_size)
        
        Returns:
            spikes: Spike train tensor (batch, timesteps, encoded_size)
        """
        batch_size = x.shape[0]
        
        # Normalize input to [0, 1] range
        x_norm = torch.sigmoid(self.gain * x + self.bias)
        
        if self.encoding_type == "rate":
            return self._rate_encoding(x_norm)
        elif self.encoding_type == "latency":
            return self._latency_encoding(x_norm)
        elif self.encoding_type == "population":
            return self._population_encoding(x)
        else:
            raise ValueError(f"Unknown encoding type: {self.encoding_type}")
    
    def _rate_encoding(self, x: torch.Tensor) -> torch.Tensor:
        """
        Rate coding: probability of spike proportional to input value.
        """
        batch_size = x.shape[0]
        device = x.device
        
        # Convert to firing probability per timestep
        prob = x * self.max_rate * self.dt / 1000.0
        prob = torch.clamp(prob, 0, 1)
        
        # Generate spikes through Poisson process
        spikes = torch.zeros(batch_size, self.num_timesteps, self.input_size, device=device)
        
        for t in range(self.num_timesteps):
            spikes[:, t, :] = (torch.rand_like(x) < prob).float()
        
        return spikes
    
    def _latency_encoding(self, x: torch.Tensor) -> torch.Tensor:
        """
        Latency coding: higher values spike earlier.
        """
        batch_size = x.shape[0]
        device = x.device
        
        # Convert to spike times (inverse: higher value = earlier spike)
        spike_times = ((1 - x) * self.num_timesteps).long()
        spike_times = torch.clamp(spike_times, 0, self.num_timesteps - 1)
        
        # Generate one-hot spike train
        spikes = torch.zeros(batch_size, self.num_timesteps, self.input_size, device=device)
        
        for b in range(batch_size):
            for i in range(self.input_size):
                t = spike_times[b, i].item()
                spikes[b, t, i] = 1.0
        
        return spikes
    
    def _population_encoding(self, x: torch.Tensor) -> torch.Tensor:
        """
        Population coding with Gaussian receptive fields.
        """
        batch_size = x.shape[0]
        device = x.device
        
        # Compute activations for each population neuron
        # x: (batch, input_size), centers: (input_size, population_size)
        x_expanded = x.unsqueeze(-1)  # (batch, input_size, 1)
        activations = torch.exp(-((x_expanded - self.centers) ** 2) / (2 * self.sigma ** 2))
        # activations: (batch, input_size, population_size)
        
        # Flatten to (batch, input_size * population_size)
        activations = activations.view(batch_size, -1)
        
        # Convert to spikes using rate coding
        prob = activations * self.max_rate * self.dt / 1000.0
        prob = torch.clamp(prob, 0, 1)
        
        spikes = torch.zeros(
            batch_size, self.num_timesteps, self.input_size * self.population_size, 
            device=device
        )
        
        for t in range(self.num_timesteps):
            spikes[:, t, :] = (torch.rand_like(activations) < prob).float()
        
        return spikes
    
    @property
    def output_size(self) -> int:
        """Return the size of encoded output."""
        if self.encoding_type == "population":
            return self.input_size * self.population_size
        return self.input_size
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

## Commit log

2026-04-14 Initial public mirror: final report, firmware, MuJoCo training, checkpoints
    - Add final_report (E90 PDF/LaTeX, figures, references)
    - Add adaptive_ondevice_hexapod (docs, firmware, ODE optimization)
    - Add hexapod_training_new without runs/ (regenerate locally)
    - Add e90_repo including released_checkpoints zips
    - Add Presentation LaTeX sources for mid-semester materials
    Made-with: Cursor
    [SG90.stl, Servo Motor.stl, hexapod.stl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]
2026-04-15 Abstract: flowing prose on bio-inspired walk, optimization, RL adaptivity
    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
2026-04-15 Intro: Kudithipudi L2M link, method-biology ties, production framing; Track III
    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
